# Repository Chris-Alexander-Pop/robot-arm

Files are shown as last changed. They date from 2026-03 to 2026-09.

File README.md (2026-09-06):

# 6-DOF Robot Arm

**Status:** early Checkpoint A ("It moves" on the bench) — not a working 6-DOF tending system.

Hobby / portfolio build: 3D-printed cycloidal joint CAD, an RS-485 motor bench, Hall homing on Arduino, and STM32 supervisory P-control for J1/J2. ROS 2 / MoveIt / Simulink trees exist as scaffolds. The headline application is not implemented.

**Stack:** STM32 (PlatformIO, P-only `JointController::Step`) · ESP32 joint-node parser · Pico + ESP32-C3 RS-485 benches · SolidWorks CAD · Python DH sandbox · ROS 2 Humble / MoveIt 2 *scaffolds* · Simulink *README only*



## Preview

<p align="center">
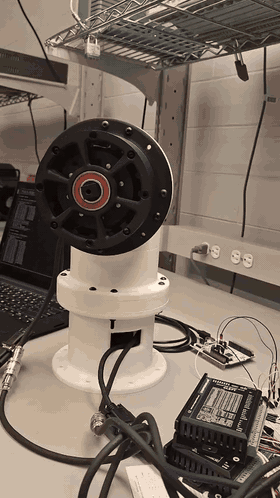
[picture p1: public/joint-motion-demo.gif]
Joint motion demo
  
</p>

<p align="center">
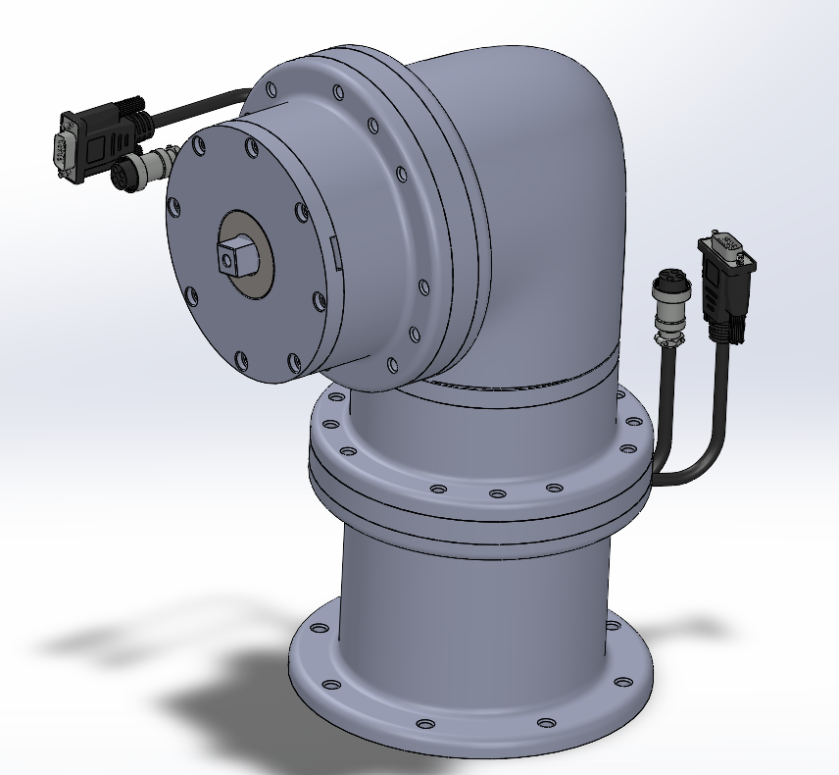
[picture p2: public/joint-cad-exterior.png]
Joint module — exterior CAD render
  
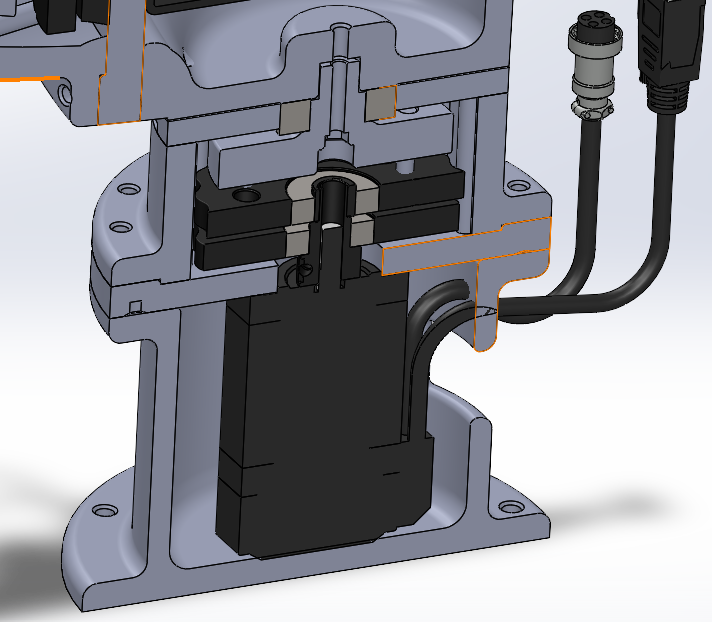
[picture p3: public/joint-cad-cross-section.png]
Joint module — cross-section CAD render
  
</p>

Bench motion clip (22–28 s from `20260516_220314_1_1.mp4`); CAD renders from SolidWorks.

## What actually works

- **Cycloidal joint CAD** under `mechanical/` — Maria is the primary CAD author (see Authorship).
- **RS-485 motor bench** — Pico master plus ESP32-C3 slaves, including a local Pico J0 STEP/DIR path on GP16/GP17: `firmware/scripts/hardware_tests/rs485_motor_bench/`.
- **Hall homing FSM** on Arduino: `firmware/scripts/hardware_tests/homing_arduino/src/main.ino`.
- **STM32 supervisory P-control** for J1/J2: `kDefaultKp = 2.0F`, Ki/Kd = 0, velocity cap `kMaxSupervisorVelocityDegS = 120.0F` in `firmware/stm32_core/lib/control/src/joint_controller.cpp`. Arduino `StepperDriver` uses AccelStepper for STEP/DIR. Native tests store commanded velocity only.
- **Native firmware tests** via `./firmware/scripts/test.sh`. **Renode smoke** in CI. **Python pytest** for the DH sandbox (`simulation/dh_solver.py`) and placeholder kinematics tests.

Gear ratios the controller uses: `kJ1MotorRevsPerJointRev = 19.0F`, `kJ2MotorRevsPerJointRev = 15.0F` in `firmware/stm32_core/lib/drivers/src/stepper_driver.cpp`. Physical cycloid pin/lobe counts are `[NEEDS MEASUREMENT]`.

## Not yet implemented

- `firmware/stm32_core/lib/bus/src/bus_master.cpp` — `BusMaster::Transaction` discards the frame and returns false (no RS-485 TX from the master).
- `firmware/joint_node/src/joint_node_app.cpp` — TODOs at the STEP/DIR + homing call site, gripper PWM, and homing FSM (`kHomePin`).
- `simulation/robot_arm_sim/kinematics/dh_model.py` — `forward_kinematics` returns the 4×4 identity.
- `software/ros2_ws/src/robot_description/urdf/mock_arm.urdf.xacro` — cylinder mock links, not CAD-derived geometry.
- `simulink/README.md` — planned Simulink / Embedded Coder tree; no `.slx` in the repo.
- `firmware/stm32_core/lib/drivers/src/encoder_driver.cpp` — MCU `ReadJointAngleDeg` returns 0.0 by design (position stays inside the CL57T/CL42T).

Checkpoint letters B–F in `docs/Application.md` are a delivery plan, not a progress report.

## Future application

The long-term target is **autonomous 3D-print bed tending** (detect completion, remove the part, start the next job). That application is not in this tree: there is no OctoPrint integration, no vision pick, and no end-to-end tending cycle. Treat it as a goal, not a capability.

## Architecture

| Layer | Location | Role today |
|---|---|---|
| Planning | `software/ros2_ws/` | ROS 2 / MoveIt 2 **scaffold** (Docker tests exist) |
| Real-time control | `firmware/stm32_core/` | UART protocol, P-only supervisor, AccelStepper on J1/J2 |
| Joint nodes | `firmware/joint_node/` | Parses bus commands; pulse generation is TODO |
| Simulation | `simulation/` | DH sandbox + identity FK placeholder + Renode smoke |
| Mechanical | `mechanical/` | SolidWorks; STEP exports where present |
| Electrical | `hardware/` | KiCad, WireViz, datasheet references |
| Model-based design | `simulink/` | README scaffold only |

Details: [`docs/ARCHITECTURE.md`](docs/ARCHITECTURE.md) · [`docs/Design_Choices.md`](docs/Design_Choices.md)

## Quickstart (~10 minutes)

**Prerequisites:** Git, Python 3.11+, [PlatformIO](https://platformio.org/) (`pio`), Docker (for ROS tests).

```bash
git clone https://github.com/Chris-Alexander-Pop/robot-arm.git
cd robot-arm
./scripts/setup.sh

# Firmware (host native tests — no hardware)
./firmware/scripts/test.sh

# Python simulation
./simulation/scripts/test.sh

# ROS / MoveIt (Docker; slower first run)
./scripts/dev.sh up
./scripts/dev.sh moveit-test
```

Full matrix: [`TESTING.md`](TESTING.md)

## Repository map

| Path | Contents |
|---|---|
| `docs/` | Requirements, architecture, journal |
| `mechanical/` | CAD (SolidWorks); see [`docs/implementation/cad_exports.md`](docs/implementation/cad_exports.md) |
| `hardware/` | KiCad, datasheets, WireViz |
| `firmware/` | STM32 C++ (PlatformIO), ESP32 joint_node, hardware benches |
| `software/` | ROS 2 workspace + Docker |
| `simulation/` | Python sim + Renode |
| `simulink/` | Planned MBD workspace (not in tree yet) |

## Verification (CI)

| Layer | Local | CI job |
|---|---|---|
| Firmware (native) | `./firmware/scripts/test.sh` | `firmware-native-tests` |
| Firmware (Renode) | build `nucleo_f401re_renode`, `simulation/renode/tests/firmware_smoke.robot` | `firmware-build-and-renode` |
| ROS / MoveIt | `./software/scripts/test.sh` | `software-behavioral-tests` |
| Simulation | `./simulation/scripts/test.sh` | `simulation-tests` |

## Team setup

- Linux/macOS: [`./scripts/setup.sh`](scripts/setup.sh)
- Windows: [`./scripts/setup.ps1`](scripts/setup.ps1)

Creates `simulation/.venv`, `.tooling/` ROS CLI tools, and Renode for headless firmware tests. Firmware uses PlatformIO, not a Python venv.

Dev helpers: [`./scripts/dev.sh`](scripts/dev.sh) / [`./scripts/dev.ps1`](scripts/dev.ps1) for Dockerized ROS.

## Authorship

`git shortlog -sne --all` on 2026-09-06 (measured before this README commit):

| Commits | Author |
|---:|---|
| 93 | Maria `<mnastase@uwaterloo.ca>` |
| 88 | Chris Alexander Pop `<chrisalexanderpop@gmail.com>` |
| 5 | dependabot[bot] |
| 4 | Fatima Syeda `<f2syeda@uwaterloo.ca>` |
| 1 | Cursor Agent `<cursoragent@cursor.com>` |

Maria is the primary CAD author. This is a shared build; firmware/bench work is not a solo project.

Re-run `git shortlog -sne --all` after new commits — do not copy these counts forward without measuring.

## Contributing

See [`CONTRIBUTING.md`](CONTRIBUTING.md) and [`firmware/CONTRIBUTING.md`](firmware/CONTRIBUTING.md). Remaining `TODO(contributor)` markers are intentional scaffolds, not abandoned files. `JointController::Step` is already P-only (not a stub).

## Licenses and third-party materials

- **Source code** (firmware, ROS, simulation, scripts): [MIT](LICENSE) — see [NOTICE](NOTICE).
- **Datasheets:** vendor URLs in [`hardware/datasheets/README.txt`](hardware/datasheets/README.txt) (PDFs not in git; download locally if needed).
- **CAD:** SolidWorks native files are proprietary format; STEP provided where applicable.
- **AccelStepper** (waspinator / Mike McCauley): GPL-3.0 or commercial — J1/J2 STEP/DIR on STM32.
- **StepperDriver** (laurb9): MIT — STEP/DIR helpers and declared `joint_node` dep.
- **MATLAB / Simulink:** optional future workflow; trademarks of The MathWorks, Inc.

## Security

Hobby / bench project only — see [`SECURITY.md`](SECURITY.md). Serial control has no authentication; use a trusted USB-UART link.

## Deep dive

- [`docs/Application.md`](docs/Application.md) — checkpoints A–F (plan, not current capability)
- [`docs/Examples.md`](docs/Examples.md) — comparison with AR4, Moveo, etc.

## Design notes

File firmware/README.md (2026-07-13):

# Firmware

Domain-level firmware for low-level embedded control: a **base STM32 master** and **ESP32 joint nodes** on a shared **RS-485** bus.

## Projects

| Directory | MCU | Role |
|:---|:---|:---|
| [`stm32_core/`](stm32_core/) | Nucleo-F401RE | Bus master, Pi UART protocol, future motion supervisor |
| [`joint_node/`](joint_node/) | ESP32 (WROOM-32 class) | Per-joint / gripper slave — **one firmware image**, multiple PlatformIO envs |
| [`lib/bus_protocol/`](lib/bus_protocol/) | — | Shared bus framing (linked by both projects) |

Architecture: [`docs/implementation/distributed_bus_architecture.md`](../docs/implementation/distributed_bus_architecture.md) · connectivity policy: [`docs/implementation/joint_node_connectivity.md`](../docs/implementation/joint_node_connectivity.md).

## Onboarding

- Contributor guide: **[CONTRIBUTING.md](CONTRIBUTING.md)**.
- Do **not** commit `compile_commands.json` under either PlatformIO project (see root `.gitignore`).
- Open the **specific** folder (`stm32_core/` or `joint_node/`) as the PlatformIO project root in VS Code.

## Build

Linux/macOS:

```bash
./firmware/scripts/build.sh              # STM32 + joint_node default env
./firmware/scripts/build.sh stm32        # STM32 only (compile, no flash)
./firmware/scripts/build.sh joint        # joint_node default env only
./firmware/scripts/build.sh joint-all    # all node_j* + node_gripper envs
```

Windows: `firmware/scripts/build.ps1` with the same optional arguments.

## Flash STM32 (Nucleo-F401RE)

Main application firmware lives in [`stm32_core/`](stm32_core/) (`src/main.cpp`). PlatformIO board/env: **`nucleo_f401re`** in [`stm32_core/platformio.ini`](stm32_core/platformio.ini). Upload uses onboard **ST-Link** (`upload_protocol = stlink`).

```bash
./firmware/scripts/upload_stm32.sh           # build + flash
./firmware/scripts/upload_stm32.sh monitor   # flash, then serial monitor @ 115200
```

Manual equivalent:

```bash
cd firmware/stm32_core
pio run -e nucleo_f401re -t upload
pio device monitor -e nucleo_f401re
```

If upload fails with `unable to connect` / `chipid 0x000`, run
[`firmware/scripts/hardware_tests/check_nucleo_stlink.sh`](scripts/hardware_tests/check_nucleo_stlink.sh)
(CN2 jumpers must be ON).

**Hardware tests** (RS-485, CL57T bench, Hall, etc.) are separate images built from
`hardware_test_main.cpp` under env **`nucleo_f401re_hwtest`** — see
[`scripts/hardware_tests/README.md`](scripts/hardware_tests/README.md).

## Test

```bash
./firmware/scripts/test.sh    # native unit tests (STM32 tree, includes bus_protocol)
```

## Flash joint nodes

```bash
cd firmware/joint_node
pio run -e node_j3 -t upload
pio device monitor
```

Unconfigured bench builds: `pio run -e esp32dev -t upload`, then serial command `NODE_ID 3`.

## Scope

- Real-time STEP/DIR and homing at the **joint node** (ESP32).
- RS-485 command/telemetry between base and nodes.
- Pi ↔ STM32 binary protocol unchanged in purpose (`lib/protocol/`).

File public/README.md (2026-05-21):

# Public media assets

README-linked visuals (committed for GitHub and local viewing).

| File | Source |
|---|---|
| `joint-cad-exterior.png` | `image.png` — SolidWorks exterior render |
| `joint-cad-cross-section.png` | `image2.png` — SolidWorks cross-section |
| `joint-motion-demo.gif` | `20260516_220314_1_1.mp4` @ 22–28 s (8 fps, 280 px wide) |
| `preview.html` | Browser gallery when Cursor preview hides images |

## Viewing in Cursor

Cursor’s default markdown renderer often **does not show local images** (forum: [local images bug](https://forum.cursor.com/t/default-cursor-markdown-renderer-fails-to-display-local-remote-images-vs-code-markdown-preview-works/160156), [feature request](https://forum.cursor.com/t/show-images-in-markdown-preview-mode/151125)).

**Option A — VS Code-style preview (recommended)**

1. Open root `README.md`.
2. If you see a WYSIWYG/preview tab, right-click the tab → **Reopen Editor With…** → **Text Editor**.
3. `Ctrl+K V` (**Markdown: Open Preview to the Side**).

**Option B — Browser**

Open `public/preview.html` in Firefox/Chrome (from the file explorer or `xdg-open public/preview.html`).

This repo sets `"workbench.editorAssociations": { "*.md": "default" }` so `.md` files prefer the text editor.

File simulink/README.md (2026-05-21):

# Simulink Workspace

> **Planned — not yet in repository**  
> MATLAB/Simulink models (`.slx`), Embedded Coder output under `codegen/output/`, and the firmware adapter described in docs are **not checked in**. Firmware today uses **hand-coded** control in `firmware/stm32_core/lib/control/`. See [`docs/implementation/simulink_workflow.md`](../docs/implementation/simulink_workflow.md).

Model-based design and embedded code generation for the 6-DOF arm. This workspace is the **control-design and codegen** counterpart to the Python/Gazebo workspace under `/simulation/`.

For the full workflow rationale, conventions, and toolbox requirements, see [`../docs/implementation/simulink_workflow.md`](../docs/implementation/simulink_workflow.md).

---

## Role in the Project

Simulink has three jobs here:

1. **Plant modeling** (`plant_models/`) — Simscape Multibody model of a joint built from the project URDF. Captures motor electrical dynamics, cycloidal reduction (with backlash + friction), and link inertia.
2. **Controller design** (`controllers/`) — Per-joint PID (and optional feed-forward / gravity-comp) designed and tuned against the plant model using PID Tuner. Output is a controller subsystem block ready for code generation.
3. **Embedded code generation** (`codegen/`) — Embedded Coder generates C source for the controller, which is linked into the PlatformIO STM32 firmware build under `firmware/stm32_core/lib/control/`.

A stretch goal is **co-simulation with ROS 2** via ROS Toolbox: Simulink plant model subscribes to `/joint_commands` from MoveIt and publishes simulated `/joint_states` back, letting controller iteration happen without spinning up Gazebo.

---

## Layout

```
simulink/
├── README.md                     # ← this file
├── plant_models/                 # Simscape Multibody / transfer-function plants
│   └── README.md
├── controllers/                  # PID + feed-forward controller designs (.slx)
│   └── README.md
├── codegen/                      # Embedded Coder configuration and generated C output
│   └── README.md
├── scripts/                      # MATLAB .m setup scripts (workspace init, param loading)
│   └── README.md
└── tests/                        # Test harnesses (unit + integration test models)
    └── README.md
```

The actual `.slx` model files are authored in MATLAB — this directory is the agreed home for them. **When codegen is implemented**, generated C under `codegen/output/` may be checked in so the firmware build does not require a MATLAB license; that output is **not in the repository yet**.

---

## Requirements

- **MATLAB R2024a or newer**
- **Simulink** (block-diagram environment)
- **Simscape** + **Simscape Multibody** (plant modeling)
- **Control System Toolbox** (PID Tuner)
- **Embedded Coder** + **Simulink Coder** (C code generation for STM32)
- **MATLAB Coder** (transitive dependency of Embedded Coder)
- *(optional)* **ROS Toolbox** — only required for the ROS 2 co-simulation stretch goal

Toolbox licensing: campus / educational MATLAB licenses typically include Simscape, Control System, and Embedded Coder. If running on a personal home license, verify Embedded Coder is included before relying on the codegen path.

---

## Onboarding

1. Open MATLAB and `cd` to this directory.
2. Run `scripts/setup_workspace.m` to load joint parameters (motor specs, gear ratios, link inertias) from the project constants into the MATLAB base workspace.
3. Open the plant model under `plant_models/joint_J1_plant.slx`.
4. Open the corresponding controller `controllers/joint_J1_pid.slx` and run PID Tuner to refine gains.
5. To regenerate C code, open `codegen/joint_pid_codegen.slx`, run `Build` (Ctrl+B); the generated source appears under `codegen/output/` and is committed.

---

## Integration with the firmware build

Generated C from Embedded Coder is dropped into `firmware/stm32_core/lib/control/generated/` and wrapped by a hand-written adapter (`joint_controller_generated.cpp`) that bridges the generated function signatures to the rest of the firmware. See [`../docs/implementation/firmware_architecture.md §2b`](../docs/implementation/firmware_architecture.md) for the integration contract.

The firmware build does **not** require MATLAB — only the regeneration of controller code does. This keeps the project buildable for collaborators without MATLAB licenses.

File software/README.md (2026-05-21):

# Raspberry Pi Software

High-level robot orchestration stack.

## Layout
- `ros2_ws/src/robot_core`: runtime control package.
- `ros2_ws/src/robot_description`: URDF/launch/rviz assets.
- `ros2_ws/src/robot_arm_moveit`: MoveIt 2 configuration and smoke tests.
- `Dockerfile`, `docker-compose.yml`: reproducible dev/runtime environment.

## Onboarding
- Start the ROS container with `./scripts/dev.sh up` from the repository root.
- Build the ROS workspace with `software/scripts/build.sh` on Linux/macOS.
- Build the ROS workspace with `software/scripts/build.ps1` on Windows.
- Run the MoveIt smoke tests with `software/scripts/test.sh` on Linux/macOS.
- Run the MoveIt smoke tests with `software/scripts/test.ps1` on Windows.

## MoveIt Bringup
- Use `./scripts/dev.sh moveit-sim` to build the workspace and launch the MoveIt + RViz simulation entry point.
- Use `./scripts/dev.sh moveit-real` to build the workspace and launch the MoveIt + RViz real-hardware entry point.

## STM32 Simulation
- Use Renode as the preferred STM32F401RE emulator for firmware-level integration tests.
- Keep the simulator entry points and test harnesses in this area so the MCU can be exercised without a physical board.
- Use the simulation package for kinematics and trajectory logic; use Renode for firmware behavior and peripheral interaction.
- Prefer headless/console mode so Renode prints to the terminal instead of opening separate analyzer windows.

## MoveIt
- `ros2_ws/src/robot_arm_moveit` holds the MoveIt 2 config package, launch entrypoint, and smoke tests.
- `sim.launch.py` and `real.launch.py` are the documented entry points; both currently wrap the shared headless MoveIt bringup and add RViz.
- Use the MoveIt launch file for planner bringup once the ROS 2 MoveIt runtime is installed in the container or host environment.

Generated ROS artifacts in `ros2_ws/build`, `ros2_ws/install`, and `ros2_ws/log` should not contain source code.

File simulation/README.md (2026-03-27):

# Simulation Workspace

Python-first sandbox for validating kinematics and trajectory behavior before hardware deployment.

## Layout
- `robot_arm_sim/`: simulation package code.
- `scripts/`: executable entry scripts for local runs.
- `tests/`: unit tests for kinematics/planning components.
- `dh_solver.py`: initial DH prototype script.
- `requirements.txt`: Python dependencies.

## Onboarding
- Create the virtual environment with the repository setup scripts.
- Run tests on Linux/macOS with `simulation/scripts/test.sh`.
- Run tests on Windows with `simulation/scripts/test.ps1`.

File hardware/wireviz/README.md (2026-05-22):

# WireViz harness diagrams

Text-based wiring docs for the 6-DOF arm. YAML in, SVG / HTML / PNG out via [WireViz](https://github.com/wireviz/WireViz).

## What is in here

| File | Scope |
|---|---|
| `10_power_distribution.yml` | AC mains, IEC inlet, E-stop, Mean Well LRS-350-24, 24V_MOTOR bus, three LM2596 buck rails. |
| `20_control_signals.yml` | STM32 Nucleo-F401RE pins, 74HC245 level shift, six driver control headers, Pi UART link. |
| `30_joint_J1_closed_loop.yml` | Detail of one closed-loop joint (CL57T + NEMA 23 + **factory encoder bundled with the kit**). Pattern repeats for J1–J4 (CL42T for J3/J4). |
| `40_joint_J5_open_loop.yml` | Detail of one open-loop wrist joint (TMC2209 + NEMA 14). AS5600 shown as an optional Phase 2 part — most builds skip it. Same shape for J6. |
| `50_homing.yml` | Six A3144 Hall sensors — each to its **ESP32 joint node** (local homing; STM32 issues bus `HOME`). |
| `35_bus_harness.yml` | RS-485 + 24V daisy chain through the arm (distributed nodes). |
| `55_wrist_encoders.yml` | Optional Phase 2 path: STM32 I2C to TCA9548A and two AS5600 boards (J5/J6 only). Omit entirely if you skip wrist encoders. |
| `60_end_effector.yml` | MG996R gripper servo (mounts inside the gripper body, not the arm), `5V_SERVO` rail, PWM signal across the J6 tool flange, optional FSR. |

These follow the contracts in:

- [`docs/implementation/electrical_design.md`](../../docs/implementation/electrical_design.md)
- [`docs/implementation/electrical_interface_map.md`](../../docs/implementation/electrical_interface_map.md)
- [`firmware/pinout.md`](../../firmware/pinout.md)

WireViz is intentionally **per-harness**, not whole-system. A high-level block view lives in `electrical_schematic_plan.md` §1 and the Mermaid sketch at the bottom of this README.

## Prerequisites

- Python 3 (the venv script makes one).
- **Graphviz** (`dot`) on your PATH. WireViz fails to render without it.
  - Arch: `pacman -S graphviz`
  - Debian/Ubuntu: `apt install graphviz`

## One-time environment

From the repository root:

```bash
./scripts/create-wireviz-venv.sh
```

Activate when needed:

```bash
source hardware/wireviz/.venv/bin/activate
```

Windows (PowerShell):

```powershell
.\scripts\create-wireviz-venv.ps1
.\hardware\wireviz\.venv\Scripts\Activate.ps1
```

## Render everything

From the repo root:

```bash
./scripts/render-wireviz.sh           # all *.yml in hardware/wireviz/, HTML+SVG
./scripts/render-wireviz.sh -c -q     # clean out/ first, quiet per-file output
./scripts/render-wireviz.sh -f hsp    # also write PNG
```

Windows (PowerShell):

```powershell
.\scripts\render-wireviz.ps1 -Clean -Quiet
.\scripts\render-wireviz.ps1 -Formats hsp
```

The script picks up every `*.yml` except `_common.yml` (prepended into every render for shared Graphviz spacing and colors). Drop a new harness file in here and rerun. Output goes to `out/` (gitignored).

Render a single file:

```bash
./scripts/render-wireviz.sh 30_joint_J1_closed_loop          # by basename
./scripts/render-wireviz.sh hardware/wireviz/55_wrist_encoders.yml  # by path
```

Or call WireViz directly if you prefer:

```bash
source hardware/wireviz/.venv/bin/activate
cd hardware/wireviz
wireviz 10_power_distribution.yml -o out -O 10_power_distribution -f hs
```

`-f hs` writes both **HTML** (with a BOM table) and **SVG** (lossless graphic). Add `p` for PNG, `t` for TSV.

## How to view the diagrams

The diagrams are SVG, so anything that opens an image or web page works:

- **Browser (recommended)** – open the HTML for the BOM + diagram inline:
  ```bash
  xdg-open out/10_power_distribution.html       # Linux
  open out/10_power_distribution.html           # macOS
  start out\10_power_distribution.html          # Windows (cmd)
  ```
- **Just the diagram** – open the SVG directly:
  ```bash
  xdg-open out/10_power_distribution.svg
  ```
- **VS Code / Cursor** – open the SVG file; the editor renders it. Right-click an SVG in the Explorer ➜ *Open Preview*.
- **Image viewer** – Eye of GNOME, qView, IrfanView, Preview, etc.
- **Static site / share** – the SVG and HTML are self-contained; you can drop them into any docs folder or email them.

If you only see XML when opening the SVG, your default app is a text editor — pick a browser or image viewer instead.

## Authoring rules learned the hard way

WireViz emits Graphviz DOT under the hood. Two pitfalls cause render failures:

1. **No leading digits in identifiers or labels.** Use `P5V_LOGIC`, not `+5V_LOGIC`. Use `P24V`, not `+24V`. Same for cable IDs (`W_PWR_LOGIC`, not `W_5V_LOGIC`).
2. **No `<` or `>` characters in `subtype:` / `notes:` text.** They terminate the HTML label early. Write `to` instead of `->`, `at least 3 A` instead of `>=3 A`.

Other conventions used here:

- **`_common.yml`** — shared `options:` and a small `tweak.append` graph directive (`nodesep`, `ranksep`) so diagrams space out consistently. Large motor drivers are split into several logical connector blocks (same physical CL57T or TMC2209) so WireViz does not draw one 15–20-pin vertical tower.
- Wire colors follow the [WireViz color codes](https://github.com/wireviz/WireViz/blob/master/docs/syntax.md#wire-colors) (`RD`, `BK`, `WH`, etc.).
- Every cable that crosses the cabinet boundary is `shield: true`.
- Joint-by-joint cables (`W_CTRL_J1` … `W_CTRL_J6`) use the same color code so a real harness label survives a swap between channels.

## Where the system view lives

WireViz is bad at one-page “whole robot” views. Use this Mermaid block diagram (rendered automatically by GitHub / VS Code / Cursor) as the index:

```mermaid
flowchart LR
  MAINS[AC mains] --> IEC[IEC C14 + fuse]
  IEC --> ESTOP[Latching E-stop]
  ESTOP --> PSU[Mean Well LRS-350-24]
  PSU --> BUS24[24V_MOTOR bus]
  BUS24 --> DRV[Drivers J1..J6]
  BUS24 --> BUCKL[LM2596 5V_LOGIC]
  BUS24 --> BUCKP[LM2596 5V_PI]
  BUS24 --> BUCKS[LM2596 5V_SERVO]
  BUCKL --> MCU[STM32 Nucleo-F401RE]
  BUCKL --> HALL[A3144 Hall homes x6]
  BUCKP --> PI[Raspberry Pi 4]
  BUCKS --> GRIP[MG996R gripper - mounts in EOAT, not arm]
  MCU -- UART --> PI
  MCU -- STEP/DIR/EN/ALARM --> DRV
  MCU -- HOME x6 --> HALL
  MCU -- PWM --> GRIP
  DRV --> MOT[Joint motors]
  MOT -. factory encoder J1-J4 inside CL57T/CL42T kit .- DRV
```

For pin-accurate detail, jump into the matching YAML and re-render.

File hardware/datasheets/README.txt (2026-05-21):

Vendor datasheet URLs for the robot arm BOM. PDFs are NOT stored in git (copyright).

Download locally into this folder if you want offline copies (files are gitignored):

  cd hardware/datasheets
  # example: curl -L -o TI_LM2596.pdf 'https://www.ti.com/lit/ds/symlink/lm2596.pdf'

If a download fails (TLS to st.com / ti.com can be flaky), open the link in a browser.

Power / analog / logic
  meanwell_LRS-350-spec.pdf
    https://www.meanwell.com/upload/pdf/LRS-350/LRS-350-SPEC.PDF
  TI_LM2596.pdf
    https://www.ti.com/lit/ds/symlink/lm2596.pdf
  TI_SN74HC245.pdf
    https://www.ti.com/lit/ds/symlink/sn74hc245.pdf
  TI_TCA9548A.pdf
    https://www.ti.com/lit/ds/symlink/tca9548a.pdf

Motors / drivers
  StepperOnline_CL57T_V40.pdf   (family doc; confirm against your V41 kit)
    https://www.omc-stepperonline.com/download/CL57T_V4.0.pdf
  StepperOnline_CL42T_manual.pdf
    https://www.omc-stepperonline.com/download/CL42T.pdf
  Trinamic_TMC2209_DigiKey_rev108.pdf   (Trinamic / Analog IC - verify YOUR breakout pins)
    https://mm.digikey.com/Volume0/opasdata/d220001/medias/docus/696/TMC2209_Rev.1.08.pdf

Sensors / homing
  Allegro_A314x.pdf   (A3144 family - legacy; consider a modern Hall part for new buys)
    https://www.allegromicro.com/~/media/Files/Datasheets/A3141-2-3-4-Datasheet.ashx
  AMS_AS5600.pdf   (AMS OSRAM AS5600 - Seeed-hosted copy)
    https://files.seeedstudio.com/wiki/Grove-12-bit-Magnetic-Rotary-Position-Sensor-AS5600/res/Magnetic%20Rotary%20Position%20Sensor%20AS5600%20Datasheet.pdf

MCU / board   (prefer official ST links in a browser)
  ST_RM0368_DM00096844_mirror.pdf   RM0368 reference manual for STM32F401xB/C/D/E
    Official: https://www.st.com/resource/en/reference_manual/dm00096844-stm32f401xb-c-and-stm32f401xd-e-advanced-arm-based-32-bit-mcus-stmicroelectronics.pdf
  ST_Nucleo64_UM1724_DM00105823_mirror.pdf   Nucleo-64 boards (MB1136), incl. NUCLEO-F401RE
    Official: https://www.st.com/resource/en/user_manual/dm00105823-stm32-nucleo64-boards-mb1136-stmicroelectronics.pdf

STM32F401RE chip datasheet:
  https://www.st.com/resource/en/datasheet/stm32f401re.pdf

MG996R gripper: no single vendor PDF; use seller diagrams + standard 3-wire hobby servo (GND, +5V, PWM).

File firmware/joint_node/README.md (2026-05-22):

# Joint node firmware (ESP32)

Distributed motor nodes: one small **ESP32** module per joint (and one for the gripper), co-located with the stepper driver. Nodes communicate on a **daisy-chained RS-485 bus** (2 twisted pairs for data + 24V/GND for power through the arm).

**Connectivity policy:** RS-485 is the **control plane** (motion, homing, watchdog). **Wi-Fi** is an optional **service plane** (config, logs, OTA) and must be **disabled during motion**. See [`../../docs/implementation/joint_node_connectivity.md`](../../docs/implementation/joint_node_connectivity.md).

## One firmware image

All nodes build from the **same source tree**. Identity is selected by:

1. **PlatformIO environment** (`node_j1` … `node_j6`, `node_gripper`) — sets `ROBOT_ARM_NODE_ID` at compile time (recommended for production).
2. **GPIO strap pins** (optional carrier PCB) — 3-bit ID when straps are populated.
3. **NVS** — persist `NODE_ID <n>` from the USB serial console (`esp32dev` / unconfigured flash).
4. **Console** — `NODE_ID 4` at runtime for bench bring-up.

## PlatformIO

Open **`firmware/joint_node/`** as the project root in VS Code.

```bash
cd firmware/joint_node
pio run -e node_j3          # build joint 3
pio run -e node_gripper -t upload
pio device monitor
```

Default env `esp32dev` leaves `ROBOT_ARM_NODE_ID=0` until configured.

## Pin map

See [`src/pinout.h`](src/pinout.h). Revise when joint carrier PCBs are laid out.

## Protocol

Shared library: [`../lib/bus_protocol/`](../lib/bus_protocol/). Full specification: [`../../docs/implementation/distributed_bus_architecture.md`](../../docs/implementation/distributed_bus_architecture.md).

## Homing (Hall sensor)

Each motor joint (IDs 1–6) has an **A3144** on `kHomePin` (see [`src/pinout.h`](src/pinout.h)). When the base STM32 sends bus command **`HOME`** (`0x23`) to this node's address, the firmware must:

1. Enable the local driver and STEP toward the configured home direction at low speed.
2. Stop on Hall trigger (active-low), zero position / step count, set homed state.
3. Report completion in the next `JOINT_STATE` response to the master poll.

The STM32 sequences homing **J1 → J6**; the Pi only sees `HOME` / `HOMED_OK` on the UART link. The gripper node does not use Hall homing.

## Wi-Fi service mode (planned)

Not implemented yet. When added:

- **MOTION** — Wi-Fi off; only RS-485 + local STEP/DIR.
- **SERVICE** — Wi-Fi on for NVS config, logs, OTA; driver disabled by default; **no** motion over Wi-Fi.

## Status

Scaffold only: bus framing, RS-485 port, enable/watchdog, and command stubs. STEP/DIR motion, **Hall homing FSM**, servo PWM, and **Wi-Fi service mode** are TODO.

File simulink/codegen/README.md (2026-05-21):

# Embedded Codegen

> **Planned — not yet in repository**  
> No `codegen/output/`, wrapper `.slx`, or firmware adapter is checked in yet. See [`../../docs/implementation/simulink_workflow.md`](../../docs/implementation/simulink_workflow.md).

Embedded Coder configuration and generated C source for the joint controllers. **Target state:** generated code checked in so the firmware (`firmware/stm32_core/`) can build without a MATLAB license.

## Layout

```
codegen/
├── README.md                     # ← this file
├── joint_pid_codegen.slx         # Wrapper model with codegen configuration
├── ert_main.tmpl                 # Custom main template (we provide our own integration)
└── output/                       # Generated C (COMMITTED)
    ├── joint_J1_pid/
    │   ├── joint_J1_pid.c
    │   ├── joint_J1_pid.h
    │   └── joint_J1_pid_types.h
    └── joint_J2_pid/
        └── ...
```

## Code Generation Settings

The wrapper model `joint_pid_codegen.slx` references the controllers from `../controllers/` and applies the following Embedded Coder configuration:

| Setting | Value | Why |
|:--|:--|:--|
| System target file | `ert.tlc` (Embedded Real-Time) | Generates production-quality C, not the larger GRT runtime |
| Hardware Implementation | ARM Cortex-M | Matches STM32 target |
| Floating point support | Single precision (`float32`) | Matches STM32F4 FPU |
| Generate reusable code | On | Lets us call the same function for multiple joints with different parameter structs |
| Pack Boolean data into bitfields | Off | Keeps the generated code easy to inspect in code review |
| File packaging format | Modular | One .c/.h per subsystem, not a single monolithic file |
| Code interface | Reusable function with parameter argument | Generated signature matches the hand-written firmware adapter |

## Integration with PlatformIO firmware

Generated source under `output/` is symlinked (or copied — TBD) into:

```
firmware/stm32_core/lib/control/generated/
```

A hand-written adapter at `firmware/stm32_core/lib/control/src/joint_controller_generated.cpp` instantiates one parameter struct per joint, calls the generated step function at 1 kHz from the existing `JointController::Step` hook, and routes the output back into the existing `StepperDriver` pulse-rate setpoint. The adapter is the **only** hand-written firmware code that touches the generated functions — everything else in the firmware stays decoupled.

This boundary is enforced so a future controller redesign (e.g., switching to LQR) does not require firmware changes outside the adapter.

## Regeneration

```matlab
% From simulink/codegen/:
load_system('joint_pid_codegen.slx');
rtwbuild('joint_pid_codegen');
```

After regeneration, commit `output/` along with the `.slx` change.

**Never edit files under `output/` by hand.** They are overwritten on every regeneration. If you need to change controller behavior, edit the model in `../controllers/`.

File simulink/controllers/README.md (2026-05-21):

# Controllers

> **Planned — not yet in repository** — no `.slx` controller models are checked in. See [`../../docs/implementation/simulink_workflow.md`](../../docs/implementation/simulink_workflow.md).

Per-joint controller designs (PID + optional feed-forward / gravity-comp). Each controller is designed against the corresponding plant model in `../plant_models/`, tuned with PID Tuner, and built into a self-contained subsystem block ready for Embedded Coder.

## Planned controllers

| File | Joint | Topology |
|:--|:--|:--|
| `joint_J1_pid.slx` | J1 | Cascaded position → velocity PID; anti-windup; saturation limits |
| `joint_J2_pid.slx` | J2 | Same topology as J1, plus a gravity-compensation feed-forward term (J2 carries the rest of the arm against gravity) |
| `joint_generic_pid.slx` | J3 – J6 | Single-loop position PID parameterized by motor/load constants — one model, many uses |
| `arm_trajectory_tracker.slx` | All 6 | Top-level controller that consumes a MoveIt-style joint trajectory and dispatches setpoints to the per-joint PIDs |

## Design discipline

- **Same controller runs in sim and on hardware.** The controller subsystem is the *exact* block that gets code-generated. No "Simulink-only" simplifications allowed — if a block can't be code-generated by Embedded Coder, it can't be in the controller.
- **Discrete-time, 1 kHz.** All controllers run at the firmware's PID loop rate (`docs/Constraints.md §3a`). Continuous-time blocks (e.g., `Integrator`) are replaced with their discrete equivalents (`Discrete-Time Integrator`).
- **Fixed-step solver, fixed-point safe.** Solver is `Fixed-step, Discrete (no continuous states)`. Where possible, data types are `single` (float32) to match what the STM32 FPU handles natively.
- **All gains exposed as tunable parameters.** Gains are referenced from the MATLAB base workspace (`Kp_J1`, `Ki_J1`, etc.), populated by `scripts/setup_workspace.m`. This makes them runtime-tunable from the firmware once the generated code is integrated, and keeps them out of the model XML.

## Tuning workflow

1. Open `joint_J1_pid.slx` connected to `joint_J1_plant.slx` in a closed loop.
2. Apply a step setpoint (e.g., 45° at t=0.1s).
3. Open PID Tuner on the PID block; tune for the response goal in `docs/Constraints.md` (rise time, overshoot, settling time).
4. Validate against a worst-case load disturbance (rated payload at full extension).
5. Commit the model with updated gains in the workspace setup script.

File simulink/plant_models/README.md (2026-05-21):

# Plant Models

> **Planned — not yet in repository** — no `.slx` plant models are checked in. See [`../../docs/implementation/simulink_workflow.md`](../../docs/implementation/simulink_workflow.md).

Simscape Multibody plant models of the arm joints. Each model captures the full electromechanical chain from driver step-pulse input to joint-angle output.

## Planned models

| File | Joint | Source dynamics |
|:--|:--|:--|
| `joint_J1_plant.slx` | J1 (Base) | NEMA 23 + CL57T (modeled as torque-speed curve) + 20:1 cycloidal (with backlash + viscous friction) + base-link inertia |
| `joint_J2_plant.slx` | J2 (Shoulder) | NEMA 23 + CL57T + 20:1 cycloidal + upper-arm inertia (gravity-loaded) |
| `arm_full_plant.slx` | All 6 | Simscape Multibody chain imported from URDF (`software/ros2_ws/src/robot_description/urdf/mock_arm.urdf.xacro`) |

## URDF import workflow

```matlab
% From the simulink/scripts/ directory:
smimport('../../software/ros2_ws/src/robot_description/urdf/mock_arm.urdf.xacro')
```

`smimport` produces a Simscape Multibody model with one Revolute Joint block per URDF joint. The imported model is then hand-augmented with:

- Motor torque-speed curves (from datasheets in `hardware/datasheets/`)
- Cycloidal backlash (modeled as a small dead-zone on torque transmission)
- Viscous + Coulomb friction (tuned to match real arm behavior — this is one of the URDF parameters that gets refined per the "simulation is the specification" philosophy)

## Validation

Plant models are validated against the constraints in [`../../docs/Constraints.md §1a`](../../docs/Constraints.md):

- Apply rated motor torque (2.0 Nm for NEMA 23) at the input.
- Verify output torque after 20:1 reduction matches the documented 40 Nm effective.
- Verify steady-state holding error under a 1 kg payload at full extension is within the ±0.5–1 mm repeatability target.

Mismatches between the plant model and the real arm get logged in [`../../docs/Journal.md`](../../docs/Journal.md) and drive URDF refinements.

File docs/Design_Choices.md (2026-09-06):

<!--
This file holds the design choices made for this project and their engineering reasoning.
Decisions are recorded here so the rationale is preserved across development phases.
-->

# Design Choices & Engineering Rationale

This document records the key design decisions for the 6-DOF robot arm, focusing on **why** each choice was made over the alternatives. Decisions are organized by subsystem.

---

## 1. Mechanical & Actuation

### 1a. Cycloidal Drives at J1–J4

**Decision**: Use **3D-printable cycloidal drives** (PETG disk + hardened steel dowel ring pins) at all four driven joints. Firmware authority for J1/J2 is 19:1 and 15:1 (`kJ1MotorRevsPerJointRev = 19.0F`, `kJ2MotorRevsPerJointRev = 15.0F`); physical counts `[NEEDS MEASUREMENT]`. J3/J4 remain design-intent 15:1 and 10:1.

**Alternatives Considered**:

| Option | Pros | Cons | Chosen? |
|:---|:---|:---|:---:|
| Planetary Gearbox (metal, off-shelf) | Very robust, no printing | Expensive (~$80–$150 per joint), heavy | ✗ |
| Harmonic Drive | Near-zero backlash, compact | Extremely expensive (~$300+) | ✗ |
| Worm Gear (3D printed) | Self-locking, cheap | High friction, low efficiency, no backdrivability | ✗ |
| Timing Belt only (J3) | Cheap, no extra housing | 3:1 belt = 2.4 Nm — **below the 3.27 Nm requirement** | ✗ |
| **Cycloidal Drive (3D printed + steel pins)** | Printable, single-stage ratios in the ten-to-twenty range, high torque density, near-zero backlash, uniform BOM | Requires PTFE grease, careful tolerances, eccentric vibration must be managed | **✓** |

**Rationale**: The cycloidal drive achieves a high ratio in a package smaller than a fist. The ring gear pins are hardened steel M4 dowels — these cannot shear; only the PETG disk is consumable. Extending cycloidals to J3 and J4 resolves the torque shortfall (see `Calculations.md §1e`) and **unifies the entire drive system**: the same dowel pins, the same print profiles, and the same assembly procedure across all four joints, simplifying fabrication and spares.

---

### 1b. NEMA 23 for J1 & J2, Not Larger (e.g. NEMA 34)

**Decision**: Use the **2.0 Nm NEMA 23** closed-loop kits as the base/shoulder motors.

**Rationale**: Firmware J2 reduction is 15:1 (`kJ2MotorRevsPerJointRev`); physical `[NEEDS MEASUREMENT]`. Output torque at J2 is `[NEEDS MEASUREMENT]` — do not reuse the old 2.0 Nm × 20 = 40 Nm figure, which used a superseded twenty-to-one design target. Going to NEMA 34 would provide more torque but:
- Larger, heavier, physically larger envelope (harder to integrate into the cycloidal housing)
- Far more expensive
- Drivers would need to operate at 5–8A, requiring a larger PSU
- Even at the firmware 15:1 (J2) / 19:1 (J1) values, PETG structural strength remains the likely limit; that comparison is unmeasured.

---

### 1c. NEMA 14 "Pancake" Motors for J5 & J6 (Wrist/Tool)

**Decision**: Use the **14HS10-0404S** NEMA 14, 26mm-long pancake steppers for joints 5 and 6.

**Rationale**: At the wrist, every gram of motor mass multiplies into additional required torque at J2 (lever arm effect). A NEMA 17 at the wrist (280g) would add ~1.5 Nm to the J2 load. The 14HS10-0404S weighs **130g** — half the NEMA 17 — and the wrist torque requirement is only ~0.15 Nm (well within its 0.14 Nm rating at low speeds, augmented by any small gearing if needed).

The wrist joints do not need the high torque of a closed-loop system, so the open-loop TMC2209 driver is sufficient. The TMC2209's **StealthChop** mode eliminates audible stepping noise, which would otherwise be very noticeable at the wrist where motor mounts are near the user.

---

### 1d. Cycloidal Drive at J3 (Elbow) — 15:1

**Decision**: Replace the originally considered GT2 belt drive at J3 with a **15:1 cycloidal drive** on the NEMA 17 (80 Ncm) motor.

**Why not belt?**
The worst-case torque at J3 is **3.27 Nm**. A 3:1 GT2 belt drive (the practical maximum before pulleys become geometrically oversized) yields only `0.80 Nm × 3 = 2.40 Nm` — a shortfall of ~27%. Increasing to 4:1 is possible but results in a 64-tooth driven pulley that is physically larger than the NEMA 17 motor body, making packaging very difficult inside the upper arm link.

**Why 15:1 specifically?**
- Yields `0.80 × 15 = 12.0 Nm` — a 3.67× safety factor over the 3.27 Nm requirement
- 15 pins is a smaller, lighter housing than the 20-pin J1/J2 design, appropriate for the NEMA 17
- 15:1 keeps motor input speed at a moderate RPM for typical joint velocities (below the estimated 1116 RPM structural resonance threshold)

**Trade-off accepted**: The cycloidal housing adds ~50–80g to Link 1 (upper arm), slightly increasing J2 load. Firmware J2 reduction is 15:1; whether that absorbs the extra mass is `[NEEDS MEASUREMENT]` (the old 40 Nm figure used a superseded twenty-to-one target).

---

### 1e. Cycloidal Drive at J4 (Forearm Twist) — 10:1

**Decision**: Use a **10:1 cycloidal drive** on the NEMA 17 (42 Ncm) motor at J4.

**Is a gearbox even necessary at J4?** The gravity torque at J4 is near-zero (the rotation axis is roughly parallel to the forearm, so the distal mass creates no gravitational moment). However, a cycloidal drive at J4 is still chosen for three reasons:

1. **Resolution**: Direct drive at 1/32 microstepping gives 0.056°/step. Through a 10:1 cycloidal, that becomes 0.0056°/step — 10× finer, enabling precise tool-roll positioning for orientation-sensitive pick-and-place.
2. **Inertial damping**: The gear reduction lowers effective reflected inertia at the output, reducing oscillation after a direction reversal — important for a lightweight wrist assembly that has little natural damping.
3. **Manufacturing uniformity**: Using the same ring pins, grease, and assembly procedure as J1/J2/J3 reduces the number of unique part types in the BOM.

**Ratio choice**: 10:1 (10 pins, 9-lobe disk) is the smallest practical cycloidal ratio. Smaller ratios have poor conjugate tooth geometry. This is the minimum necessary to gain the resolution and damping benefits without adding unnecessary housing mass.

---

### 1f. Vibration Mitigation Strategy

**Decision**: Implement a tiered vibration mitigation strategy across all cycloidal drives.

**Why is vibration a concern?** Each cycloidal drive's eccentric cam (a 608ZZ bearing offset ~1mm from the motor shaft centreline) creates a rotating centrifugal imbalance force $F = m \cdot e \cdot \omega^2$. At 600 RPM motor input, this is ~79 mN per drive. With 4 drives on the arm, unmitigated vibration accumulates and is amplified at the end-effector.

**Mitigation decisions (in priority order):**

| Measure | Implementation | Cost | Joints |
|:---|:---|:---:|:---|
| **Counterweight disk** | Second 608ZZ at 180° on rear motor shaft | ~$2/joint | J1–J4 (mandatory) |
| **Twin-disk cycloidal** | Two disks 180° out of phase; cancels torque ripple | Doubles disk print time | J1, J2 (high duty cycle) |
| **S-curve trajectories** | MoveIt 2 jerk-limited profiles (`joint_limits.yaml`) | Software only | All joints |
| **1/32 microstepping** | CL42T DIP switch (J3/J4); CL57T already supports | No cost | J3, J4 |
| **PTFE grease** | Standard lubrication requirement | Already in BOM | J1–J4 |

**Rationale**: The counterweight is the most impactful and cheapest fix — it statically balances the rotating assembly and eliminates the imbalance force at **all speeds**. The twin-disk addition at J1/J2 addresses torque ripple, which is a secondary vibration source distinct from the imbalance. S-curves prevent the firmware from exciting the estimated 18.6 Hz PETG link resonance during acceleration phases. Together, these measures should reduce vibration to a level imperceptible during normal pick-and-place.

---

### 1g. PETG over PLA or ABS

**Decision**: Use **PETG filament** as the primary structural material.

**Rationale**:
- **vs. PLA**: PLA has a glass transition temperature of ~60°C. A stepper motor running at 50% duty cycle in an enclosure can heat motor mounts to 55–70°C, causing PLA to soften and deform under load. PETG's 80°C Tg provides safe headroom.
- **vs. ABS**: ABS warps severely during printing (requires enclosure, specific bed temperatures) and releases unpleasant fumes. PETG prints reliably on an open printer with a PEI-coated bed.
- **vs. ASA/Nylon**: Stronger materials, but require specialized hardware; PETG is optimal for the shop-printable constraint.

---

## 2. Electronics & Control

### 2a. Closed-Loop Stepper Kits (CL57T / CL42T) over Open-Loop

**Decision**: Use **integrated closed-loop stepper kits** for J1–J4 instead of open-loop drivers (TB6600, A4988, etc.).

**Alternatives Considered**:

| Option | Pros | Cons |
|:---|:---|:---|
| Open-loop steppers | Cheap, simple | Skip steps under load → arm loses position without knowing |
| Open-loop + separate AS5600 encoder | Position monitoring | STM32 must implement full correction loop; complexity |
| **Closed-loop kit (CL57T/CL42T)** | Encoder+correction built into driver IC | Costs ~2–3× more than an open-loop driver |
| Servo motors (Dynamixel) | Very capable, compact | Expensive ($50–$200 per joint), proprietary protocol |

**Rationale**: The CL57T and CL42T drivers perform closed-loop correction **within the driver itself** — if the motor skips a step, the driver detects the encoder mismatch and corrects it without any STM32 involvement. This dramatically simplifies firmware and eliminates missed-step failures, which are the #1 reliability problem with open-loop stepper arms. The cost premium over TB6600 drivers is ~$40 per joint — well worth it for a reliable, repeatable arm.

---

### 2b. STM32 + Raspberry Pi Hierarchy over Single-Board Solution

**Decision**: Use a **two-tier compute architecture** (STM32 for real-time, RPi 4 for planning) rather than trying to do everything on one device.

**Why not Raspberry Pi alone?**
Linux is not a real-time OS. Even with `PREEMPT_RT` patches, the Pi's scheduler can introduce millisecond-scale jitter in motor control loops. Stepper motors require microsecond-precise pulse timing. A 1ms timing jitter causes audible vibration and velocity ripple.

**Why not Arduino/ESP32 alone?**
An Arduino Mega or ESP32 can generate precise step pulses, but has insufficient RAM and compute to run ROS 2, trajectory planning, or IK solving. The ESP32's RTOS is capable, but the software ecosystem (ROS 2, MoveIt) is built for Linux.

**Conclusion**: The STM32 handles microsecond-level timing in hardware (no OS, hardware timers), while the Pi handles the math-heavy planning layer in software. This is the same architecture used by professional robot arms (e.g., the UR5 uses a dedicated FPGA + a PC for this split).

---

### 2c. 74HC245 Logic Level Shifter (Not Resistor Divider)

**Decision**: Use the **74HC245 octal bus transceiver** for 3.3V → 5V level shifting, not a simple resistor voltage divider.

**Rationale**: A resistor divider (e.g., 1kΩ/2kΩ) works for **downward** shifting (5V → 3.3V). For upward shifting (3.3V → 5V), a resistor divider cannot amplify voltage — you need an active buffer. The 74HC245 has a propagation delay of ~8ns, well within the STM32's minimum STEP pulse width. It handles all 8 STEP/DIR signals simultaneously for just ~$3.

---

### 2d. Mean Well LRS-350-24 PSU (Not 24V Laptop Adapter)

**Decision**: Use the **Mean Well LRS-350-24** industrial enclosed switching PSU, not a commodity 24V adapter.

**Rationale**:
- Laptop-style 24V adapters typically max out at 3–5A — insufficient for the 13.8A peak requirement
- The LRS series has proper **EMI filtering** — critical for preventing motor switching noise from propagating back into the logic supply and corrupting I2C encoder reads
- The **IEC C14 panel connector** allows a proper fused inlet with an E-stop in the AC line — critical for safe operation
- Mean Well has published MTBF figures and certifications; unbranded adapters do not

---

## 3. Software Architecture

### 3a. ROS 2 (Humble) over Custom Communication Protocol

**Decision**: Use **ROS 2 with MoveIt 2** for all high-level control, rather than writing a custom control stack.

**Rationale**: The ROS 2 ecosystem provides:
- **MoveIt 2**: Battle-tested motion planning with OMPL, collision avoidance, and IK solvers
- **`ros2_control`**: A standardized hardware abstraction layer — swap simulation/real hardware by changing one parameter
- **`robot_state_publisher`**: Automatic URDF-based transform tree for RViz and collision checking
- **Gazebo integration**: The simulation stack plugs directly into the control stack with no code changes

Writing a custom equivalent would take months and would lack the testing coverage of industry-standard packages.

**Trade-off**: ROS 2 on a Raspberry Pi remains computationally heavy. Running in Docker adds overhead. The **Pi 4** improves headroom over older Pi generations for MoveIt / planning; if latency becomes an issue, migrating to a Pi 5 or a small x86 NUC is straightforward — the ROS 2 code is identical.

---

### 3b. Docker for ROS 2 Deployment

**Decision**: Run all ROS 2 nodes in **Docker containers** managed by `docker-compose`.

**Rationale**:
- ROS 2 Humble requires Ubuntu 22.04. The Pi may run a different OS version for other tasks — Docker keeps the ROS environment isolated.
- The `docker-compose.yml` file is a single source of truth for the entire software environment, making setup reproducible from a fresh SD card in minutes.
- Container volumes mount the `/software/` directory, so code changes are reflected immediately without rebuilding the image.

---

### 2e. Joint Node Links: RS-485 Control + Optional Wi-Fi Service (Not Wi-Fi Motion)

**Decision**: Each ESP32 joint node uses **RS-485** as the **only** path for motion, homing, enable, and watchdog traffic to/from the STM32 bus master. **Wi-Fi** (ESP32-C3 built-in) is **optional** and used **only** in a dedicated **service mode** for configuration, logs, and OTA — **Wi-Fi is off or logically disabled during motion**.

**Alternatives considered**:

| Option | Pros | Cons |
|:---|:---|:---|
| **Wi-Fi / BLE only** (Pi talks to all nodes wirelessly) | No RS-485 harness | Jitter, dropouts, EMI on metal arm, higher idle current, weak safety story |
| **RS-485 only** (no Wi-Fi) | Simplest RF | OTA and per-node config require USB serial at each link |
| **RS-485 + optional Wi-Fi service** (chosen) | Reliable control; convenient bench tooling | Two stacks to maintain; must enforce mode separation in firmware |

**Rationale**: The arm already needs a differential bus for deterministic multi-drop control near motor EMI. Wi-Fi is still useful for human-facing tasks (flash firmware, set `NODE_ID`, read logs) without betting homing or MoveIt streaming on a 2.4 GHz link. Full policy: [`implementation/joint_node_connectivity.md`](implementation/joint_node_connectivity.md).

---

## 4. Decisions Deferred (TBD)

| Decision | Options | Blocking Factor |
|:---|:---|:---|
| Wrist encoder (AS5600 on J5/J6) | Add or skip | Test open-loop accuracy first; add if drift is a problem |
| Collision avoidance method | OctoMap (camera) vs. static scene | Camera integration TBD |
| User interface | Web dashboard vs. RViz markers vs. joystick | Depends on final workflow preference |
| Gripper type | Parallel jaw vs. vacuum vs. magnetic | Depends on target objects for pick-and-place |
| J4 ratio refinement | Stay at 10:1 or reduce to 8:1 | Depends on measured CAD mass — smaller ratio = lighter housing |

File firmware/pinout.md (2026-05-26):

# STM32F401RE Pinout Decisions

This document tracks the pin assignment strategy for the STM32F401RE firmware target.

**Board alignment:** Matches `platformio.ini`: **Nucleo-F401RE** (`board = nucleo_f401re`).
It is intentionally a design note, not a generated CubeMX file.
The current firmware code is still a scaffold, so the final pin map should be reviewed
again before hardware bring-up.

## Why This Exists

The STM32F401RE has many multifunction pins, but only a subset can be used at the same
height of the design without conflicts. The important part is not just "what pins exist",
but which peripheral functions must be reserved together:

- SWD debug/programming pins must stay available.
- The host communication link needs a stable UART or USB path.
- Encoder feedback needs a clean I2C bus.
- Six stepper axes need six STEP outputs and six DIR outputs.
- Homing, fault, and emergency-stop signals can quickly consume the remaining GPIO.

That means the pinout should be planned as a budget, not as a collection of isolated pins.

## Current Firmware State

The code in `stm32_core/src/main.cpp` is still a single-axis prototype.
It currently uses placeholder Arduino-style pin definitions and a single AS5600 encoder.
The real multi-axis firmware will likely move the pin assignments into a central header
or board-specific configuration file so that all drivers share one source of truth.

## Design Rules

### 1. Reserve the essential system pins first

These pins should not be repurposed for robot I/O:

- `PA13` / `PA14`: SWDIO and SWCLK for programming and debug
- `NRST`: reset line
- `BOOT0`: boot mode strap

If a board variant exposes a user button or LED on a shared pin, confirm it does not
interfere with the intended robot functions.

### 2. Keep host communication separate from debug

The robot link to the Raspberry Pi should not depend on the same interface used for flashing
or console output unless that is a deliberate choice.
For this project, the preferred pattern is:

- One UART for the robot control link
- SWD kept for programming/debugging
- Optional secondary debug console only if there are enough free pins

This keeps the motion-control path independent of local development convenience.

### 3. Reserve one I2C bus for optional wrist feedback

J1–J4 use closed-loop driver kits whose factory motor encoder is read **inside the driver**; the STM32 never touches I2C for those joints. The shared I2C bus on this design only matters for the **optional** AS5600 add-on at J5 / J6.

Recommended bus selection (kept reserved even when no AS5600 is fitted, so a Phase 2 retrofit is a wiring change rather than a firmware redesign):

- `I2C1` on `PB6` (SCL) and `PB7` (SDA)

Reasons:

- Common on STM32F4 boards
- Easy to route
- Leaves the higher-value pins free for time-critical signals
- A TCA9548A multiplexer is only required if **both** J5 and J6 get an AS5600 (since both share the fixed `0x36` address). With one wrist encoder, the AS5600 sits directly on the bus.

### 4. Keep STEP/DIR pins on plain GPIO unless hardware timers are proven necessary

The current firmware scaffold uses software-stepped motion control.
That means the stepper outputs only need reliable digital outputs for now.
If the design later migrates to timer-driven pulse generation, the pin map should be
rechecked against timer-capable alternate functions.

## Proposed Pin Budget

The table below is the working allocation strategy.
Some entries are firm, and others are still candidates because the final joint count and
fault strategy may change.

| Function | Count | Suggested STM32F401RE Resource | Status |
| --- | ---: | --- | --- |
| SWD debug/programming | 2 | `PA13`, `PA14` | Reserved |
| Host control link | 2 | `USART1` or equivalent external UART | Needed |
| Encoder bus | 2 | `I2C1` on `PB6`, `PB7` | Preferred |
| Step outputs | 6 | Six GPIO outputs | Needed |
| Direction outputs | 6 | Six GPIO outputs | Needed |
| Home sensors | 6 | Six interrupt-capable inputs | Needed |
| Driver alarms | 6 | Six fault inputs, or a grouped fault line | Open |
| E-stop | 1 | Dedicated interrupt input | Needed |
| Spare expansion | 1+ | GPIO or I2C expander | Strongly recommended |

## Recommended Functional Grouping

### Motion outputs

Use one GPIO pair per joint:

- J1: STEP + DIR
- J2: STEP + DIR
- J3: STEP + DIR
- J4: STEP + DIR
- J5: STEP + DIR
- J6: STEP + DIR

This keeps the firmware simple and makes it easy to map each joint to a controller slot.

### Encoder feedback

For J1–J4, position comes from the closed-loop driver itself (RS-485 from the CL57T / CL42T) — no STM32 GPIO is consumed by the driver-side encoder. For J5 / J6, the optional wrist AS5600 (if fitted) lives on `I2C1`. A TCA9548A multiplexer is needed only when both wrist AS5600 boards are populated, since they share the fixed `0x36` address.

### Fault handling

The most likely place for pin pressure is fault handling.
If every driver has its own ALARM line plus a separate home sensor, the board can run out of
clean GPIO faster than expected.
Two practical options exist:

1. Keep each fault line discrete and use more of the GPIO budget.
2. Group less critical faults through an I2C GPIO expander or a wired-OR fault bus.

The second option is usually the safer choice if the board variant proves tight.

## Candidate Board-Level Allocation

This is a practical starting point for review, not a final electrical drawing.
It favors keeping the high-value buses on stable pins and spreading the stepper outputs
across available GPIO banks.

| Signal Group | Candidate Pins | Notes |
| --- | --- | --- |
| SWD | `PA13`, `PA14` | Do not use for robot I/O |
| Robot UART | `PA9`, `PA10` | Good candidate for the Pi link if available |
| I2C1 | `PB6`, `PB7` | Encoder bus |
| J1 STEP/DIR | `PB0`, `PB1` | General GPIO |
| J2 STEP/DIR | `PB10`, `PB11` | General GPIO |
| J3 STEP/DIR | `PB12`, `PB13` | General GPIO |
| J4 STEP/DIR | `PB14`, `PB15` | General GPIO |
| J5 STEP/DIR | `PC6`, `PC7` | General GPIO |
| J6 STEP/DIR | `PC8`, `PC9` | General GPIO |

This layout keeps the core buses separate from the motion outputs and leaves the lower
GPIO range available for sensors and fault inputs.
The exact pin numbers should still be checked against the specific package and board variant
before hardware wiring is finalized.

## Open Decisions

- Whether the host link should use UART or USB CDC
- Whether each motor driver needs its own alarm input or a shared fault line is enough
- **Distributed (production):** Hall homing inputs are on each **ESP32 joint node** (`joint_node/src/pinout.h`), not on the Nucleo — see [`docs/implementation/distributed_bus_architecture.md`](../docs/implementation/distributed_bus_architecture.md)
- **Centralized (bench only):** whether six homing sensors tie to STM32 GPIO or an I2C GPIO expander
- Whether the final firmware uses Arduino-style GPIO control or STM32 HAL/CubeMX configuration
- Whether a board-specific `pinout.h` should be introduced once the final map is settled

## Recommendation

For now, treat this as the working pinout policy:

- Reserve SWD and reset pins permanently.
- Put the Pi link on one UART.
- Put all encoders on one I2C bus.
- Give each joint a dedicated STEP/DIR pair.
- Use the remaining GPIO for homes, alarms, and E-stop.
- Add an I2C GPIO expander if the board runs out of clean interrupt-capable inputs.

That approach fits the STM32F401RE resource limits without overcommitting the design too early.

---

## RS-485 bus master (distributed architecture)

When using ESP32 joint nodes ([`docs/implementation/distributed_bus_architecture.md`](../docs/implementation/distributed_bus_architecture.md)), the Nucleo acts as the **RS-485 master** only — it no longer bit-bangs STEP/DIR for remote joints.

| Function | Pin | Nucleo label | Notes |
|:---|:---|:---|:---|
| `RS485_TX` | `PA9` (`USART1_TX`) | **D8** | To MAX485 `DI` — Arduino header (M-F dupont) |
| `RS485_RX` | `PA10` (`USART1_RX`) | **D2** | From MAX485 `RO` |
| `RS485_DE` | `PA4` | **A2** | HIGH = transmit; tie `/RE` to `DE` if separate |
| USB debug `Serial` | `PA2` / `PA3` (`USART2`) | — | ST-Link VCP — do not use for RS-485 |
| Pi `UART_TX/RX` | (future) | — | Production may move host UART off `PA9`/`PA10` |

**Termination:** 120 Ω at the Nucleo transceiver (bus end). Second terminator at the gripper node.

Joint-node GPIO (STEP/DIR/ENABLE/ALARM/HOME) lives in [`joint_node/src/pinout.h`](joint_node/src/pinout.h).

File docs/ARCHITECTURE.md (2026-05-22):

# Architecture index

One-page map into the design documentation. The repository is a **monorepo** spanning
mechanical CAD, electrical design, STM32 firmware, ROS 2 software, Python simulation,
and (planned) Simulink model-based design.

## System context

| Layer | Location | Role |
|---|---|---|
| Planning / orchestration | `software/ros2_ws/` | ROS 2 Humble, MoveIt 2, hardware bridge |
| Real-time control | `firmware/stm32_core/`, `firmware/joint_node/` | STM32 bus master + Pi UART; ESP32 per-joint STEP/DIR, Hall homing |
| Digital twin | `simulation/` | Python kinematics, URDF, Renode firmware smoke |
| Mechanical | `mechanical/` | SolidWorks models; STEP exports where present |
| Electrical | `hardware/kicad/`, `hardware/wireviz/` | Schematics, harness diagrams |
| Model-based design (planned) | `simulink/` | README scaffold only — not in tree yet |

**High-level story:** [`Application.md`](Application.md) · [`Design_Choices.md`](Design_Choices.md) · [`Scope.md`](Scope.md)

## Implementation deep dives

| Topic | Document |
|---|---|
| Firmware (STM32, ESP32 nodes, protocol) | [`implementation/firmware_architecture.md`](implementation/firmware_architecture.md) |
| Distributed RS-485 bus + homing | [`implementation/distributed_bus_architecture.md`](implementation/distributed_bus_architecture.md) |
| RS-485 control + optional Wi-Fi service | [`implementation/joint_node_connectivity.md`](implementation/joint_node_connectivity.md) |
| Software (ROS 2, bridge, MoveIt) | [`implementation/software_architecture.md`](implementation/software_architecture.md) |
| Simulation & Gazebo | [`implementation/simulation_environment.md`](implementation/simulation_environment.md) |
| Simulink workflow (planned) | [`implementation/simulink_workflow.md`](implementation/simulink_workflow.md) |
| Mechanical design | [`implementation/mechanical_design.md`](implementation/mechanical_design.md) |
| Electrical / KiCad | [`implementation/electrical_design.md`](implementation/electrical_design.md) |

## Build & verify

- Setup: [`../scripts/setup.sh`](../scripts/setup.sh)
- Tests: [`../TESTING.md`](../TESTING.md)
## Subsystem READMEs

- [`../firmware/README.md`](../firmware/README.md)
- [`../software/README.md`](../software/README.md)
- [`../simulation/renode/README.md`](../simulation/renode/README.md)
- [`../simulink/README.md`](../simulink/README.md) (scaffold)

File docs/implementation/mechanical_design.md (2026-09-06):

# Mechanical Design & Kinematics

<!--
This document details the mechanical architecture, actuator selection, power transmission strategy,
structural materials, and kinematic approach for the 6-DOF robot arm.
-->

## 1. Design Goals & Payload Estimate

The arm is designed for **desktop-scale pick-and-place operations**, targeting an estimated payload of **0.5 – 1.0 kg** at the end-effector. The total arm reach is targeted at **~500mm** (from shoulder to wrist) based on the link-length breakdown below. These targets will be validated in simulation before final hardware procurement.

**Gear-ratio authority.** Firmware uses `kJ1MotorRevsPerJointRev = 19.0F` and `kJ2MotorRevsPerJointRev = 15.0F` in `firmware/stm32_core/lib/drivers/src/stepper_driver.cpp`. Physical pin/lobe counts are `[NEEDS MEASUREMENT]`. Effective-output-torque products that assumed twenty-to-one reduction are superseded.

---

## 2. Actuator Selection

The motor stack is split into three tiers based on joint position and torque requirement. Mounting heavier motors closer to the base is a deliberate strategy to minimize the **moving moment of inertia** — the further mass sits from the base pivot, the more energy is wasted just swinging the arm itself.

| Joint | Description | Motor | Driver | Torque | Gearing | Eff. Output Torque |
|:---|:---|:---|:---|:---|:---|:---|
| J1 | Base Rotation | NEMA 23 (2.0 Nm) | CL57T Closed-Loop | 2.0 Nm | Cycloidal 19:1 (firmware) | `[NEEDS MEASUREMENT]` |
| J2 | Shoulder Pitch | NEMA 23 (2.0 Nm) | CL57T Closed-Loop | 2.0 Nm | Cycloidal 15:1 (firmware) | `[NEEDS MEASUREMENT]` |
| J3 | Elbow Pitch | NEMA 17 (80 Ncm) | CL42T Closed-Loop | 0.80 Nm | Cycloidal 15:1 | **~12 Nm** |
| J4 | Forearm Twist | NEMA 17 (42 Ncm) | CL42T Closed-Loop | 0.42 Nm | Cycloidal 10:1 | **~4.2 Nm** |
| J5 | Wrist Pitch | NEMA 14 (14 Ncm) | TMC2209 Open-Loop | 0.14 Nm | Direct | **0.14 Nm** |
| J6 | Tool Roll | NEMA 14 (14 Ncm) | TMC2209 Open-Loop | 0.14 Nm | Direct | **0.14 Nm** |

> **Note on Closed-Loop Kits**: J1–J4 use integrated closed-loop stepper kits (`1-CL57T-S20-V41` for J1/J2, `1-CL42T-S08-V41` for J3, `1-CL42T-S04-V41` for J4) which include the motor, matched driver, and encoder wiring. The built-in encoder closes the loop at the driver level — no external AS5600 required on these joints.

---

## 3. Gearing & Power Transmission

All four driven joints (J1–J4) use **cycloidal drives**. This eliminates the torque shortfall that belt-only drives had at J3, unifies the manufacturing process (same print profiles, same components), and removes belt-stretch as a source of positional error.

### 3a. Cycloidal Drive Design (All J1–J4)

A cycloidal drive is a compact, high-ratio speed reducer that achieves a large gear ratio in a single short stage. Its key properties:
- **3D Printable**: Ring pins are hardened steel dowel pins (3–5mm); the disk and housing are PETG. No metal machining.
- **High Ratio in Compact Form**: 10:1–30:1 in a package shorter than the motor itself.
- **Near-Zero Backlash**: The disk is always in contact with multiple pins simultaneously — no gear mesh "slop".
- **Load Shared Across Many Pins**: Force is distributed across ~half the pins at any moment, drastically reducing peak contact stress vs. a single-tooth mesh.

**Ratio selection per joint** (CAD intent, not counted on hardware). Firmware J1/J2 constants are 19.0 and 15.0; physical `[NEEDS MEASUREMENT]`.

| Joint | Pins (N) CAD intent | Disk Lobes (N-1) CAD intent | Ratio in controller | Rationale |
|:---:|:---:|:---:|:---:|:---|
| J1 | `[NEEDS MEASUREMENT]` | `[NEEDS MEASUREMENT]` | 19:1 firmware | Highest torque demand |
| J2 | `[NEEDS MEASUREMENT]` | `[NEEDS MEASUREMENT]` | 15:1 firmware | Not identical to J1 in firmware; do not assume a shared housing ratio |
| J3 | 15 | 14 | 15:1 | Resolves belt shortfall; smaller housing fits NEMA 17 envelope |
| J4 | 10 | 9 | 10:1 | Low torque demand; smallest housing, minimizes added mass |

**Key Components (per drive unit):**
- **Eccentric cam**: One `608ZZ` bearing press-fit onto the motor shaft, offset by **1.0 mm** from centre
- **Counterweight disk**: A second `608ZZ` (or equivalent mass) press-fit on the rear shaft at 180° offset — cancels eccentric imbalance and reduces vibration (see §3c)
- **Cycloidal disk**: 3D-printed PETG with epitrochoidal tooth profile; toleranced at +0.1 to +0.15 mm clearance to ring pins
- **Ring gear pins**: Hardened steel M4 dowel pins (4mm ⌀) press-fit into the housing — they cannot shear; only the disk is consumable
- **Output bearings**: `6806` or `6808` thin-section bearings at J1/J2; `6804` or `6806` at J3/J4 (smaller motor, smaller housing)
- **Output pin carrier**: A second set of output pins (same M4 dowels) in the output flange that engage the drive holes in the cycloidal disk — transmit rotation without transmitting the eccentric motion

> **Lubrication is mandatory**: Pack synthetic PTFE grease into every cycloidal assembly before first use. Dry running will melt and destroy the PETG disk within minutes of sustained load.

---

### 3b. Vibration in Cycloidal Drives & Mitigation

The rotating eccentric cam creates a **centrifugal imbalance force** that, if unmitigated, causes the whole arm to vibrate — particularly at J3 and J4 which are cantilevered further from the base.

#### Source of Vibration

The eccentric cam assembly (608ZZ bearing, ~20g, offset 1.0 mm from the shaft centreline) acts as an unbalanced rotating mass:

$$F_{imbalance} = m_{ecc} \times e \times \omega^2$$

- At **300 RPM** → ω = 31.4 rad/s → F ≈ **20 mN** (negligible)
- At **1000 RPM** → ω = 104.7 rad/s → F ≈ **220 mN** (noticeable, especially at end-effector)
- At **2000 RPM** → ω = 209.4 rad/s → F ≈ **880 mN** (significant — unacceptable for precision tasks)

High motor speeds on the *input* side of a high-ratio cycloidal drive are common (output moves slowly, but motor spins fast). Normal operational input speeds of 300–600 RPM are expected for smooth trajectories. RPM at the firmware J1/J2 ratios for a given output rate is `[NEEDS MEASUREMENT]`.

#### Mitigation Strategies (Priority Order)

1. **Counterweight Disk (Mandatory)**: A second bearing or custom-machined/printed disk of matching mass is mounted on the **rear** of the motor shaft, diametrically opposite (180° offset from) the eccentric cam. This statically balances the rotating assembly, eliminating the imbalance force entirely at all speeds. **Must be implemented on all four cycloidal drives.**

2. **Twin-Disk (Dual-Phase) Cycloidal (Strongly Recommended for J1/J2)**: Use two cycloidal disks stacked axially, keyed 180° out of phase on the same eccentric. Their eccentric forces cancel each other continuously. This also doubles the load capacity and smooths the torque ripple from the individual disk lobes engaging pins. J1 and J2 should use this design given their higher duty cycles and the fact that any base vibration is amplified up the full arm length.

3. **S-Curve Velocity Profiles (Software — Mandatory)**: MoveIt 2 trajectory parameterization must use **S-curve** (jerk-limited) profiles rather than trapezoidal profiles. Trapezoidal profiles produce instantaneous acceleration changes that stimulate resonant modes of the cycloidal drive and PETG links. S-curves limit the rate of change of acceleration (jerk), preventing resonance excitation. Configure in `ompl_planning.yaml` and the `joint_limits.yaml` jerk parameters.

4. **Microstepping (1/32 or Higher)**: Higher microstepping reduces the per-step torque impulse from the stepper motor. Each individual step is smaller, reducing the amplitude of periodic forcing at the stepping frequency. The CL42T and CL57T support up to 1/256 microstepping — the default of 1/16 is a minimum; 1/32 is recommended for J3/J4.

5. **PTFE Grease (Mandatory, also Dampens)**: A well-greased cycloidal drive is significantly quieter and more vibration-damped than a dry one. The grease film between the disk and ring pins acts as a viscous damper that absorbs high-frequency vibration energy.

---

## 4. Structural Materials & Manufacturing

### 4a. Primary Structure: 3D-Printed PETG
PETG is chosen over PLA or ABS for the following reasons:

| Property | PLA | PETG | ABS |
|:---|:---|:---|:---|
| Glass Transition Temp | ~60°C | **~80°C** | ~100°C |
| Layer Adhesion | Good | **Excellent** | Fair |
| Warp Resistance | Good | **Excellent** | Poor |
| Impact Resistance | Brittle | **Good flex** | Good |
| Post-print difficulty | Easy | **Easy** | Hard (fumes, warp) |

Motors generate significant heat. PETG's 80°C glass transition temperature provides headroom that PLA simply does not.

### 4b. Fasteners & Inserts
- **M3 / M4 / M5 Alloy Steel Bolts & Nuts**: Standard metric hardware for all structural connections
- **M3×5mm Brass Heat-Set Inserts**: Press-in with a soldering iron; creates a permanent metallic threaded boss inside PETG that withstands high-torque motor mounting without stripping
- **Blue Loctite**: Applied to all motor mount fasteners to prevent vibration-induced loosening

### 4c. Bearings
- **J1/J2 Output (Cycloidal)**: `6806` or `6808` thin-section bearing — carries the full structural (axial bending) load at the base and shoulder joints
- **J3/J4 Output (Cycloidal)**: `6804` or `6806` thin-section bearing — appropriate for the smaller NEMA 17 housing profile
- **Eccentric Cam (All Cycloidal)**: `608ZZ` bearings — one per disk stage as the eccentric cam rolling element
- **Counterweight (All Cycloidal)**: Second `608ZZ` (or printed mass) on the rear motor shaft, 180° offset from the eccentric cam
- **Motor shafts must NEVER carry structural loads** — motor shafts are only coupled for torque transmission. All bending/axial forces must pass through the output bearing.

---

## 5. End-Effector

The end-effector is a self-contained sub-assembly that bolts to the **J6 tool flange**. It is mechanically and electrically independent from the joint motors, which keeps tool changes from disturbing the arm wiring.

- **Gripper Actuator — `MG996R` metal-gear micro servo**.
  - **Mounting**: inside the gripper body itself (3D-printed claw / parallel-jaw assembly) that bolts to the J6 tool flange. The MG996R is **not** mounted in the arm wrist — J6 already has its own NEMA 14 stepper for tool roll. The gripper servo only opens / closes the jaws.
  - **Power**: dedicated `5V_SERVO` rail from a third LM2596 buck off `24V_MOTOR` (see [electrical_design.md §1b](electrical_design.md)). It is **not** sharing the `5V_LOGIC` or `5V_PI` rails — stall spikes from the servo would otherwise glitch the MCU.
  - **Signal**: a single ~50 Hz PWM line from one STM32 timer pin (e.g. `PA8 / TIM1_CH1`). 3.3 V drive is sufficient for a hobby servo's high-impedance signal pin, so no level shifter is required.
  - **Wiring across the wrist**: all EOAT signals (`5V_SERVO`, `GND_M`, `PWM`, optional `FSR`) cross the wrist on a single 4-pin tool-flange connector. See [`hardware/wireviz/60_end_effector.yml`](../../hardware/wireviz/60_end_effector.yml).
- **Optional Force Feedback**: a **Force Sensitive Resistor (FSR)** on the gripper fingertip pad, fed through a 10k voltage divider into a STM32 ADC pin. Enables a grip-force PID to prevent crushing delicate objects. Also lives inside the gripper body, not the arm.

---

## 6. Denavit-Hartenberg (DH) Parameters

The arm's kinematics are parameterized using the **Modified DH convention**. These parameters define the geometric relationship between each consecutive joint frame and are used directly in both the Python IK/FK solver and the URDF model.

| Joint | a (mm) | α (deg) | d (mm) | θ (variable) | Notes |
|:---:|:---:|:---:|:---:|:---:|:---|
| J1 | 0 | 90 | d1 | θ1 | Base rotation; d1 = height of base |
| J2 | L1 | 0 | 0 | θ2 | Shoulder pitch; L1 = upper arm length |
| J3 | L2 | 90 | 0 | θ3 | Elbow pitch; L2 = forearm length |
| J4 | 0 | -90 | d4 | θ4 | Forearm twist |
| J5 | 0 | 90 | 0 | θ5 | Wrist pitch |
| J6 | 0 | 0 | d6 | θ6 | Tool roll; d6 = flange offset |

> **L1, L2, d1, d4, d6** are physical link lengths determined by the CAD model. These will be updated once the first prototype joints are dimensioned.

---

## 7. Source CAD & export workflow

Authoritative mechanical CAD is in **`mechanical/sw-models/`** (SolidWorks). To keep the repo and reviews usable (without relying on Windows-only binary formats alone), see **[CAD source files & export conventions](cad_exports.md)** for which formats to export per part, assembly, and drawing, and how to name them.

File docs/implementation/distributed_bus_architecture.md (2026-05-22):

# Distributed Bus Architecture (RS-485 + ESP32 Joint Nodes)

The arm moves from a **centralized** control box (one STM32, long STEP/DIR harnesses) to **distributed joint nodes**: a small **ESP32** next to each motor driver, daisy-chained on a **4-conductor** link through the links.

| Pair | Signals | Purpose |
|:---|:---|:---|
| **A** | `RS485_A`, `RS485_B` | Half-duplex differential bus (twisted pair) |
| **B** | `24V_MOTOR`, `GND_M` | Motor rail + return (gauge per segment current) |

Logic 5V/3.3V is **buck-converted locally** at each node from `24V_MOTOR` (not passed on the 4-wire harness).

---

## Why RS-485 (not CAN)

| Criterion | RS-485 | CAN 2.0 |
|:---|:---|:---|
| ESP32 integration | UART + MAX3485 + DE pin | TWAI peripheral (no extra controller on many boards) |
| Driver ecosystem | CL57T already exposes RS-485 for telemetry | Would not reuse driver UART without adapters |
| Harness | 2-wire differential + termination at ends | Same |
| Software cost | Master-scheduled polling (simple) | Hardware arbitration (slightly more complex frames) |

**Decision:** **RS-485 @ 921600 baud**, master-slave polling from the base **STM32 Nucleo**.

**Also decided:** ESP32 joint nodes may use **Wi-Fi only as an optional service channel** (config, logs, OTA) — **disabled during motion**. See [`joint_node_connectivity.md`](joint_node_connectivity.md).

---

## Topology

```text
[Raspberry Pi] --UART--> [STM32 master @ base] --RS-485-->
      J1 node --> J2 node --> J3 --> J4 --> J5 --> J6 --> Gripper node
      (each: ESP32 + driver + motor phases local)
```

- **Daisy chain:** `BUS_IN` / `BUS_OUT` + `PWR_IN` / `PWR_OUT` on each joint PCB.
- **Termination:** 120 Ω between A/B at the **base master** and at the **last node** (gripper/wrist) only.
- **Rotation (J1):** The same 4 conductors pass through the base swivel or slip ring; bus width stays fixed.

---

## Node map

| Node ID | Role | Motor / actuator |
|:---:|:---|:---|
| `1` | J1 | NEMA 23 + CL57T |
| `2` | J2 | NEMA 23 + CL57T |
| `3` | J3 | NEMA 17 + CL42T |
| `4` | J4 | NEMA 17 + CL42T |
| `5` | J5 | NEMA 14 + TMC2209 |
| `6` | J6 | NEMA 14 + TMC2209 |
| `7` | Gripper | MG996R (PWM) |
| `0` | Master | STM32 (not on bus as a slave) |
| `0xFF` | Broadcast | Heartbeat / discovery |

---

## Frame format

Implemented in [`firmware/lib/bus_protocol/`](../../firmware/lib/bus_protocol/).

```text
[0xAA][0x55][DST][SRC][CMD][LEN][PAYLOAD...][CRC16_LE]
```

- **CRC16-CCITT** over `DST` through end of payload (poly `0x1021`, init `0xFFFF`).
- **Max payload:** 32 bytes. **Max frame:** 40 bytes.

### Command IDs

| CMD | Name | Direction | Payload |
|:---:|:---|:---|:---|
| `0x20` | `SET_JOINT_TARGET` | Master → joint | `position_deg` (f32), `velocity_deg_s` (f32) |
| `0x21` | `JOINT_STATE` | Joint → master | `position_deg`, `velocity_deg_s`, `fault_flags` (u8) |
| `0x22` | `ENABLE` | Master → node | `u8` 1=on, 0=off |
| `0x23` | `HOME` | Master → joint | empty — starts **autonomous homing** on that node (see § Homing) |
| `0x24` | `HEARTBEAT` | Master → broadcast | empty |
| `0x25` | `SET_GRIPPER` | Master → gripper | `duty` f32 (0=open, 1=closed) |
| `0x26` | `GRIPPER_STATE` | Gripper → master | `duty`, `fault_flags` |

Pi ↔ STM32 **UART packets** (`protocol/packet_codec`, `0x10`/`0x11`) are unchanged in role: the Pi still talks only to the base MCU; the STM32 translates to bus transactions.

---

## Homing (Hall sensors on joint nodes)

Homing is **not** executed on the base STM32. Each motor joint has an **A3144 Hall effect sensor** and a fixed magnet at the mechanical zero; the sensor connects to the local **ESP32** (`HOME` GPIO in [`firmware/joint_node/src/pinout.h`](../../firmware/joint_node/src/pinout.h)). The gripper node has no Hall homing — it only reports PWM state.

### Trigger and ownership

| Layer | Role |
|:---|:---|
| **Pi** | Sends `HOME` (`0x04`) on the Pi↔STM32 UART link when the operator or ROS stack requests homing |
| **STM32** | **Orchestrates** only: disables motion commands, issues bus `HOME` (`0x23`) to nodes **in order** J1 → J2 → … → J6 (see [`../Constraints.md §3e`](../Constraints.md)), waits for each node to finish, then replies `HOMED_OK` to the Pi |
| **ESP32 joint node** | **Executes** homing autonomously after a valid addressed `HOME` frame: STEP/DIR sweep, Hall edge detect, stop, zero local step counter / `position_deg` |

Until homing completes system-wide, the STM32 must reject or ignore absolute position commands (policy in [`firmware_architecture.md`](firmware_architecture.md) §2d).

### Per-node homing FSM (ESP32)

When `HOME` (`0x23`) is received for this node's ID:

1. Assert **ENABLE**, set **DIR** toward the configured “seek home” direction, run **STEP** at a low fixed frequency (profile per joint).
2. Poll **`kHomePin`** (A3144, active-low when the magnet is present).
3. On trigger: stop pulses immediately, latch **position = 0°**, clear velocity, set an internal **homed** flag.
4. Respond on the next master poll with `JOINT_STATE` (position near 0, homed indicated in `fault_flags` or equivalent — TBD in firmware).

If **ALARM** asserts or no **HEARTBEAT** within the watchdog window during homing, the node disables the driver and reports fault.

### Sequence (system)

```text
Pi --HOME--> STM32
                |
                +-- HOME node 1 --> [J1 ESP32: sweep + Hall] --> JOINT_STATE (homed)
                +-- HOME node 2 --> [J2 ESP32: ...]
                ...
                +-- HOME node 6 --> [J6 ESP32: ...]
                |
Pi <--HOMED_OK-- STM32
```

Optional post-home move to a safe **rest pose** is a higher-level policy (STM32 streams `SET_JOINT_TARGET` after all nodes report homed).

---

## Timing and rates

- **Baud:** 921600 (adjust if cable length / EMI requires).
- **Master cycle:** Broadcast heartbeat, then poll nodes `1..7` (request + response each).
- **Target aggregate rate:** ~100–200 Hz full-arm updates; nodes interpolate/set STEP locally between polls.
- **Watchdog:** Each slave disables its driver if no valid `HEARTBEAT` (or addressed command) within **500 ms** (`docs/Constraints.md`).

---

## Firmware layout

| Path | Role |
|:---|:---|
| [`firmware/lib/bus_protocol/`](../../firmware/lib/bus_protocol/) | Shared framing + types (STM32 + ESP32) |
| [`firmware/joint_node/`](../../firmware/joint_node/) | ESP32 slave — **one codebase**, ID via env / NVS / straps |
| [`firmware/stm32_core/lib/bus/`](../../firmware/stm32_core/lib/bus/) | RS-485 master scaffold |
| [`firmware/stm32_core/lib/protocol/`](../../firmware/stm32_core/lib/protocol/) | Pi serial protocol (unchanged semantics) |

### Flashing joint nodes

```bash
cd firmware/joint_node
pio run -e node_j4 -t upload    # production: baked-in ID
pio run -e esp32dev -t upload   # bench: then serial `NODE_ID 4`
```

---

## Hardware notes (per node)

- **RS-485 transceiver:** e.g. MAX3485; **DE** high during TX, low for RX.
- **STEP/DIR/ENABLE/ALARM:** ESP32 GPIO → driver (5 V via level shifter where required).
- **Homing:** A3144 on `HOME` pin → ESP32 GPIO only (not routed to the base harness). Magnet placement defines mechanical zero per link.
- **Gripper node:** Dedicated `5V_SERVO` buck; PWM ~50 Hz on ESP32 LEDC.

Placeholder GPIO map: [`firmware/joint_node/src/pinout.h`](../../firmware/joint_node/src/pinout.h).

---

## Migration from centralized wiring

| Before | After |
|:---|:---|
| 6× STEP/DIR/ENABLE/ALARM to control box | Local to each node |
| Motor phases routed to box | Phases **at joint** (short) |
| STM32 bit-bangs all STEP timers | ESP32 per joint; STM32 schedules bus |
| `20_control_signals.yml` long bundles | `40_bus_harness.yml` (4-conductor daisy) |

Centralized firmware paths remain buildable during bring-up; enable distributed mode when `BusMaster` UART backend is wired.

---

## Open work (scaffold)

- [ ] STM32 `BusMaster::Transaction` UART + DE driver
- [ ] ESP32 STEP/DIR timer loop + homing FSM
- [ ] Gripper LEDC mapping
- [ ] Wireviz + KiCad net names for `RS485_A/B`, daisy connectors
- [ ] `hw_interface` assumes aggregated joint state from STM32 (no Pi bus exposure)
- [ ] Optional Wi-Fi service mode per [`joint_node_connectivity.md`](joint_node_connectivity.md)

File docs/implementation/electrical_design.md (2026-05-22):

# Electrical Design

<!--
This document details the complete electrical architecture:
power system, compute hierarchy, motor drivers, sensors, wiring, and safety systems.
-->

## 1. Power System

### 1a. Main Power Supply — Mean Well LRS-350-24

The selected PSU is the **Mean Well LRS-350-24** (350W, 24V, 14.6A). This choice is driven by the combined peak current draw of all 6 motors:

| Motor | Driver | Peak Current | Count | Subtotal |
|:---|:---|:---|:---:|:---|
| NEMA 23 (2.0 Nm) | CL57T | ~4.0A | 2 | 8.0A |
| NEMA 17 (80 Ncm) | CL42T | ~3.0A | 1 | 3.0A |
| NEMA 17 (42 Ncm) | CL42T | ~2.0A | 1 | 2.0A |
| NEMA 14 (Pancake) | TMC2209 | ~0.4A | 2 | 0.8A |
| **Total (Theoretical Max)** | | | | **~13.8A** |

The LRS-350-24 provides **14.6A**, giving a small but safe margin. Critically, **software motion constraints** are enforced to ensure J1 and J2 (the two highest-current joints) are never both at peak torque simultaneously, keeping the real-world draw well below the PSU limit.

> **Why 24V?** Stepper motor back-EMF scales with RPM. A higher bus voltage allows the driver to force current through the motor windings faster, maintaining torque at higher speeds. Running at 12V would cause torque rolloff at speeds required for smooth arm motion.

### 1b. Logic Power — LM2596 Buck Converters

The 24V rail is **stepped down** to lower voltages for logic components:

| Rail | Voltage | Consumers |
|:---|:---|:---|
| Logic 5V | 5V | 74HC245, Hall sensors; **Nucleo** may take **5 V** from this rail **or** from the ST-Link USB port (never **24 V**) |
| Logic 3.3V | 3.3V | **STM32 core and GPIO** at **3.3 V** — **Nucleo onboard regulator** derives this from the board’s **5 V** (outputs are **~3.3 V**, not 5 V) |
| Pi Power | 5V/≥3A | Raspberry Pi 4 (via dedicated buck converter for isolation; size for peak CPU + USB load) |
| Servo 5V | 5V | MG996R gripper only (third buck or UBEC from `24V_MOTOR`; not shared with logic/Pi rails) |

The LM2596-based buck converter modules are compact and inexpensive. A **separate** buck converter powers the Pi to isolate it from the motor noise on the main logic 5V rail.

**STM32 dev board vs “3.3 V” confusion**: The **microcontroller GPIO** uses **3.3 V logic levels** (a pin driven HIGH is ~3.3 V, not 5 V). The **Nucleo-F401RE** is normally powered from **5 V USB** (ST-Link port) or the board’s 5 V input; the board’s LDO creates **3.3 V** for the STM32 chip. **STEP/DIR from the MCU are therefore 3.3 V signals** — the **74HC245** shifts them to **5 V** for CL57T/CL42T inputs configured for 5 V TTL. Do **not** connect the **24 V motor rail** to any STM32 or Nucleo logic pin.

### 1c. Safety — E-Stop & IEC C14 Inlet

- **E-Stop Button**: Latching mushroom-head button wired **in series** with the PSU's AC input. Pressing it immediately cuts all power to the arm — zero software dependency on safety.
- **IEC C14 Inlet with Fuse**: A panel-mounted C14 connector with an integrated fuseholder. The fuse is sized to the PSU's rated input current as the last-resort overcurrent protection.

---

## 2. Compute Hierarchy

The system uses a **three-tier compute architecture**: planning on the Pi, bus mastering on the base STM32, and **per-joint** real-time control on ESP32 modules next to each driver.

```
[ Raspberry Pi 4 ]          <-- High-Level (ROS 2, MoveIt 2, IK/FK)
        |
    USB / UART
        |
    [ STM32 @ base ]        <-- Bus master, Pi protocol, system safety
        |
    RS-485 (2-wire) + 24V/GND daisy chain through the arm
        |
  [ESP32+driver] x6  +  [ESP32 gripper]
        |
   Motors local to each joint
```

- The **Raspberry Pi 4** runs ROS 2 in Docker containers. It handles trajectory planning, inverse kinematics, and user-facing interfaces. It does **not** perform any real-time motor control.
- The **STM32** at the control box polls joint nodes on **RS-485** (921600 baud) and bridges telemetry/commands to the Pi over UART. See [`distributed_bus_architecture.md`](distributed_bus_architecture.md).
- Each **ESP32 joint node** generates STEP/DIR (or TMC UART) for its local driver, runs homing on the local Hall sensor, and disables the driver on bus watchdog timeout. Optional **Wi-Fi** is for bench service only (off during motion) — [`joint_node_connectivity.md`](joint_node_connectivity.md).

A **legacy centralized** layout (one STM32, all drivers in the box) remains documented in wireviz `20_control_signals.yml` for bring-up; production targets the **4-conductor bus harness** (`hardware/wireviz/35_bus_harness.yml`).

---

## 3. Motor Drivers

### 3a. CL57T — Closed-Loop Driver (J1 & J2, NEMA 23)

The CL57T is a dedicated closed-loop stepper driver. It accepts a STEP/DIR signal from the STM32 and uses the bundled encoder feedback to internally correct for missed steps **without** requiring the STM32 to handle the correction loop. Key settings:

- **Current Range**: 0–8.0A (configured via DIP switches for the 2.0 Nm motor)
- **Input Voltage**: 20–50V DC (24V rail is ideal)
- **Step Resolution**: Configurable from full-step to 1/256 microstepping
- **Alarm Output**: Pulls low on fault (stall, overcurrent) — wired to STM32 interrupt pin

### 3b. CL42T — Closed-Loop Driver (J3 & J4, NEMA 17)

Same closed-loop principle as CL57T but sized for NEMA 17 current ranges:

- **J3** (80 Ncm motor): CL42T configured up to 3.0A
- **J4** (42 Ncm motor): CL42T configured up to 2.0A

### 3c. TMC2209 — Open-Loop Driver (J5 & J6, NEMA 14)

The NEMA 14 wrist motors are driven by TMC2209 modules, the standard for silent, smooth stepper control:

- **StealthChop2**: Near-silent operation at speeds below the threshold (important for lab environment)
- **SpreadCycle**: Falls back to high-efficiency full-power mode for demanding moves
- **Current**: Configured for 0.4A (NEMA 14 rated current) via VREF trimmer or UART
- **No Encoder Required**: The wrist joints carry minimal load, and microstepping resolution at 1/16 or 1/32 is sufficient. If precision becomes an issue, external AS5600 encoders can be added.

### 3d. 74HC245 — Logic Level Shifter

The STM32 outputs **3.3V logic** signals (STEP/DIR). The CL57T and CL42T industrial drivers expect **5V logic** levels. The 74HC245 octal bus transceiver shifts all 3.3V STEP/DIR signals to 5V:

- 1 chip handles 4 signal pairs (8 lines) — one per joint per direction
- Powered from `5V_LOGIC`; wire `DIR` (direction select) and `/OE` per the manufacturer datasheet so **STM32-side ports see 3.3 V CMOS inputs** and **driver-side ports drive 5 V** toward the CL57T/CL42T inputs (often **B→A** when shifting “up” toward the motor driver)

---

## 4. Sensors & Feedback

### 4a. Built-in Encoder Feedback (J1–J4)

The closed-loop kits (CL57T and CL42T) include a **motor-mounted encoder**. The driver reads this internally, closing the current loop without STM32 involvement. The STM32 can still query the driver's actual position register over RS-485 for position telemetry if needed.

### 4b. AS5600 Magnetic Encoders (Optional, J5–J6 only)

> **AS5600 is not part of the J1–J4 wiring.** The closed-loop CL57T/CL42T kits (sec 4a) close the position loop **inside the driver** using their bundled motor encoder. Adding an AS5600 to those joints is redundant and is **not** in the design.

For the open-loop wrist joints, AS5600 is treated as a **Phase 2 / contingency** part:

- **When to add it**: only if measured open-loop drift on J5 or J6 becomes unacceptable in practice. Wrist precision is usually dominated by gear backlash and tool inertia, not stepper resolution, so most builds will skip the AS5600 entirely.
- **Principle**: A small diametrically magnetized magnet glued to the motor shaft rotates above the AS5600 IC. The IC measures field angle and outputs 12-bit position (0–4095 counts per revolution) over I2C.
- **Address conflict**: All AS5600s share the fixed I2C address `0x36`. A **TCA9548A** multiplexer is therefore only needed if **both** wrist encoders are fitted; one AS5600 alone can sit directly on the STM32 I2C bus.
- **Resolution**: 12 bits = 4096 steps/rev → **0.088°/count** raw, well under what the wrist mechanically resolves anyway.

### 4c. A3144 Hall Effect Sensors — Homing

On each joint (J1–J6), an **A3144 Hall effect sensor** and a small neodymium magnet establish the **absolute zero (home) position** at startup:

- The sensor is wired to the **ESP32 joint node** on that link (`HOME` on the local sensor header), not to the base STM32.
- After the base STM32 sends a bus **`HOME`** command, the node sweeps slowly until the Hall output triggers, then stops and zeros its local position reference.
- The base STM32 **orchestrates** homing order (J1 → … → J6); it does not bit-bang STEP/DIR or read Hall pins for remote joints in the distributed harness.

This eliminates reliance on limit microswitches, which have mechanical wear, and keeps homing timing on the same MCU that generates STEP pulses.

---

## 5. Wiring & Signal Integrity

### 5a. Wire Gauge Selection

| Circuit | AWG | Rationale |
|:---|:---|:---|
| Motor phase wires (NEMA 23) | 18 AWG | Up to 4A continuous; silicone jacket for flex and heat |
| Motor phase wires (NEMA 17/14) | 22 AWG | Lower current; smaller and lighter |
| Logic signals (STEP/DIR, I2C) | 22 AWG shielded | Shielding prevents motor PWM noise from corrupting encoder data |
| Power distribution bus | 16 AWG | Main 24V bus from PSU to driver terminal blocks |

### 5b. Connectors

- **GX16 Aviation Connectors**: Locking metal connectors on the control box panel for motor cables. Rated for high vibration.
- **Wire Ferrules (Crimped)**: All wires inserted into screw-terminal blocks (drivers, PSU) are terminated with ferrules. Bare stranded wire under a screw terminal can cold-flow and loosen over time — ferrules prevent this.
- **PET Sleeving & Drag Chain**: Motor cables are bundled in braided PET sleeving and routed through a drag chain at the base rotation joint to protect them from fatigue during continuous J1 sweeps.

### 5c. Harness — Bus vs centralized

**Distributed (target):** Each joint PCB exposes `BUS_IN` / `BUS_OUT` (RS-485 A/B + 24V/GND). Motor phases terminate at the joint. Base board holds STM32 + RS-485 transceiver + Pi UART + 120 Ω termination.

**Centralized (bring-up):** Custom perfboard "hat" on the Nucleo with STEP/DIR/ENABLE to all drivers, 74HC245, Pi UART — see `20_control_signals.yml`.

### 5d. STM32 Breakout / Protoboard (base)

- RS-485 transceiver + DE/RE GPIO
- UART header for Raspberry Pi 4
- 24V distribution to first bus segment
- Optional: legacy STEP/DIR headers during migration

---

## 6. Validation Strategy Without Hardware

If no physical components are on hand, the electrical side can still be validated at the level that matters most right now: power, interfaces, fault handling, and wiring assumptions.

### 6a. What Can Be Checked Now

- **Power budget math**: Recheck PSU headroom, per-rail current, fuse sizing, and startup margin.
- **Interface contracts**: Define exact STEP/DIR/ENABLE polarity, logic levels, fault-pin behavior, and connector pinouts.
- **Signal integrity assumptions**: Confirm that 3.3V to 5V shifting, pullups, and cable lengths are reasonable for the chosen wiring scheme.
- **Safety behavior**: Document what should happen on E-stop, driver alarm, serial timeout, and encoder failure.
- **Harness documentation**: Freeze a wiring table so the physical build later matches the software assumptions.

### 6b. What Is Not Worth Simulating Yet

- Detailed stepper winding physics for every motor.
- Closed-loop behavior of the CL57T/CL42T drivers unless vendor models are available.
- Full EMI/noise behavior of the real harness.

Those are only useful once the actual parts and cable lengths exist. Before that, they add complexity without improving the design much.

### 6c. Recommended No-Hardware Work Products

1. A pin-by-pin electrical map for the STM32, level shifter, drivers, sensors, and power rails.
2. A current budget table that includes peak, average, and fault-state draw.
3. A fault-state matrix showing how the firmware and hardware should respond to each failure.
4. A bench bring-up checklist for when the first PSU, driver, and motor are available.

The corresponding docs are:

- [Electrical interface map](electrical_interface_map.md)
- [Electrical schematic plan](electrical_schematic_plan.md)
- [Electrical bring-up checklist](electrical_bringup_checklist.md)

For this project, that means the immediate electrical deliverable is a **clean interface specification**, not a full circuit simulator.

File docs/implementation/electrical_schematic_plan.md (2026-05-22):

# Electrical Schematic Plan

This is the KiCad-ready block plan for the robot arm electrical system. It describes how the schematic should be split into sheets and what each sheet should contain.

**KiCad project (draft):** [hardware/kicad/robot_arm/robot_arm.kicad_pro](../../hardware/kicad/robot_arm/robot_arm.kicad_pro)

## 1. Top-Level Power Flow

```text
AC mains
  -> IEC C14 inlet + fuse
  -> latching E-stop
  -> Mean Well LRS-350-24
  -> 24V motor bus
  -> motor drivers
  -> logic buck converters
  -> STM32 / sensors / Raspberry Pi 4
```

## 2. Recommended Schematic Sheets

### 2a. Power Entry Sheet

Include:
- IEC C14 inlet
- Fuse holder
- E-stop switch in series with the mains feed
- PSU output terminals
- Main 24V distribution node
- Ground / chassis bonding points

### 2b. Logic Power Sheet

Include:
- 24V to 5V buck converter for logic
- Separate 24V to 5V buck converter for Raspberry Pi 4 (`5V_PI`, ≥3A capable)
- Bulk capacitance on the 5V rail
- Test points for 24V, 5V, and 3.3V

### 2c. STM32 Control Sheet

Include:
- STM32 header / breakout
- 74HC245 level shifter
- UART to Raspberry Pi 4
- RS-485 transceiver to daisy-chained ESP32 joint nodes (see [`distributed_bus_architecture.md`](distributed_bus_architecture.md))
- I2C bus to TCA9548A (optional wrist AS5600 only)
- RS-485 to joint-node daisy chain (no per-joint STEP/DIR at base in distributed mode)
- Pi UART; optional legacy STEP/DIR only for bench bring-up

### 2d. Motor Driver Sheet

Include one repeated channel block per joint:
- Driver power input from 24V rail
- STEP / DIR / ENABLE input signals
- ALARM output
- Motor connector
- Optional encoder connector for closed-loop channels

### 2e. Joint Node Sheet (per link)

Repeat one hierarchical sheet per joint node PCB (ESP32 + local buck + MAX3485 + driver):

- A3144 Hall home sensor header → **ESP32 `HOME` GPIO** (boot homing on the node)
- STEP / DIR / ENABLE / ALARM to the local driver
- RS-485 and 24V daisy in/out
- Optional AS5600 header on **J5/J6 nodes only** (Phase 2)

### 2f. Base Sensor Sheet (optional wrist path)

On the **base** control board only when needed:

- I2C pullups (4.7k to `5V_LOGIC`) for optional wrist AS5600 path (legacy centralized wiring)
- AS5600 + TCA9548A **depopulated by default**

> Production homing does **not** route `HOME_J1`…`HOME_J6` to the Nucleo. Hall sensors live on joint-node boards. Default build: no AS5600s, no mux at the wrist unless drift forces it.

## 3. Net Naming Convention

Use a consistent naming scheme so the schematic remains readable:

- `24V_MOTOR`
- `5V_LOGIC`
- `5V_PI`
- `STM32_STEP_J1` ... `STM32_STEP_J6`
- `STM32_DIR_J1` ... `STM32_DIR_J6`
- `STM32_EN_J1` ... `STM32_EN_J6`
- `DRV_ALARM_J1` ... `DRV_ALARM_J6`
- `NODE_HOME` (per joint-node sheet; not `HOME_Jx` at base in distributed mode)
- `I2C_SCL`, `I2C_SDA`
- `UART_TX`, `UART_RX`

## 4. Design Rules for the Schematic

- Keep motor power separate from logic power until the connector boundary.
- Put all decoupling capacitors near the load they serve.
- Draw the fault path so it is obvious that a driver alarm can disable motion.
- Label every net that crosses a sheet boundary.
- Use repeated hierarchical sheets for the six joints instead of duplicating one-off wiring.
- Keep the schematic human-readable first; PCB optimization comes later.

## 5. KiCad Implementation Order

1. Draw the power-entry and buck-converter sheets.
2. Add the STM32 control sheet and confirm all logic nets.
3. Build one reusable motor-driver sheet for a single joint.
4. Replicate that sheet for all six joints.
5. Add the sensor sheet and verify the I2C and home inputs.
6. Assign footprints only after the schematic netlist is stable.

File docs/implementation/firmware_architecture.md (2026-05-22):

# Firmware Architecture (STM32)

<!--
This document details the low-level firmware running on the STM32 microcontroller:
its responsibilities, control loop design, communication protocol, and safety logic.
-->

## 1. Overview & Role

The STM32 at the base is the **bus master** and **Pi gateway**. Joint-level real-time work (STEP/DIR, homing, driver ENABLE, local watchdog) runs on **ESP32 modules** co-located with each driver — see [`distributed_bus_architecture.md`](distributed_bus_architecture.md). Optional **Wi-Fi** on each ESP32 is for config/logs/OTA only and is **off during motion** — see [`joint_node_connectivity.md`](joint_node_connectivity.md).

The STM32 does not perform trajectory planning or inverse kinematics — those remain on the Raspberry Pi. It receives target joint states over UART, issues RS-485 commands to nodes `1..7`, aggregates telemetry, and enforces system-wide safety (serial timeout, e-stop policy).

**Why a dedicated microcontroller instead of doing everything on the Pi?**
A Linux-based system (including the Raspberry Pi running ROS 2) is not a real-time OS. The scheduler can preempt any process for milliseconds at a time. A stepper motor requires pulse trains generated with microsecond-level precision — a 1ms jitter in pulse timing produces audible stuttering, vibration, and degraded position accuracy. The STM32 solves this with hardware timers that generate STEP pulses entirely in hardware, irrespective of software load.

---

## 2. Responsibilities

### 2a. Step Pulse Generation (STEP/DIR)

The STM32 uses **hardware timer peripherals** (TIM1, TIM2, etc.) in output-compare mode to generate STEP pulses. The pulse frequency directly maps to motor speed:

```
steps_per_second = (target_velocity_deg_per_sec / 1.8) * microstep_divisor
pulse_period_us  = 1,000,000 / steps_per_second
```

*Example*: At 1/16 microstepping, moving at 90°/s = 800 steps/rev × (90/360) × 16 = **3200 pulses/sec** → 312.5 µs per pulse.

The timer auto-reloads at this period. No `delay()` calls, no busy-waiting. The CPU is free to run the PID loop and handle UART simultaneously.

### 2b. Closed-Loop PID Control

Although the CL57T and CL42T drivers handle their own internal closed-loop correction at the driver level, the STM32 can still run a **supervisory position control loop** at the system level when the firmware needs behavior above the driver's built-in correction:

1. **Setpoint**: Target joint angle received from the Raspberry Pi (degrees).
2. **Process Variable**: Current actual joint angle. For J1–J4 this comes from the closed-loop driver itself (over RS-485 or the driver's internal step register). For J5–J6 it comes from the homed step counter, or from an AS5600 if one has been fitted as an optional add-on.
3. **Error**: `e(t) = setpoint - actual`
4. **PID Output**: Adjusts the step pulse frequency (velocity) fed to the driver.

```
u(t) = Kp * e(t) + Ki * ∫e(t)dt + Kd * de(t)/dt
```

The control loop runs at **≥ 1 kHz** (every 1ms) using a SysTick or dedicated timer interrupt. The PID gains (Kp, Ki, Kd) are **stored in flash** for each joint independently and can be tuned over the serial command interface without reflashing.

This makes the PID layer useful for:
- smoothing setpoint changes from ROS / MoveIt,
- compensating for load-dependent lag on joints that expose external position feedback,
- tuning homing and slow approach moves,
- and providing a consistent control abstraction if a joint is later converted from closed-loop driver feedback to external encoder feedback.

It is not meant to replace the driver's own internal correction loop on J1-J4.

> **For the open-loop TMC2209 wrist joints (J5/J6)**: The PID loop is effectively open-loop (encoder feedback not available by default). The STM32 simply commands position by counting pulses from the homed reference. If drift becomes a problem, AS5600 encoders can be added at the wrist.

> **Planned — not yet in repository:** Simulink Embedded Coder output and `joint_controller_generated.cpp` are **not checked in**. Firmware **today** uses only the hand-coded path below.

**Two implementations of this PID layer are planned**, switchable per joint at compile time once codegen exists:

| Path | Source | Status |
|:--|:--|:--|
| **Hand-coded** | `firmware/stm32_core/lib/control/src/pid_controller.cpp`, `joint_controller.cpp` | **In tree** — baseline; Checkpoint A |
| **Generated** | `firmware/stm32_core/lib/control/generated/` + adapter `joint_controller_generated.cpp` | **Planned** — Checkpoint C target; see [`simulink_workflow.md`](simulink_workflow.md) |

The generated path will satisfy the Simulink → firmware contract in [`../Constraints.md §3c`](../Constraints.md): fixed-step discrete at 1 ms, `float32` numerics, velocity-command output, no dynamic allocation. The hand-coded path uses the same interface so swapping is intended to be a single header `#define` when codegen lands.

### 2c. Encoder Reading (I2C — optional path, J5/J6 only)

> The CL57T / CL42T closed-loop kits on **J1–J4** report their position via the driver itself; the STM32 does not poll an external AS5600 for those joints. The I2C / mux code path only exists for **optional** wrist feedback on J5 / J6.

When an AS5600 encoder is connected to a wrist joint:

1. If both J5 and J6 are fitted with AS5600 boards, the STM32 first writes the target channel to the **TCA9548A** I2C multiplexer (address `0x70`). With only one wrist AS5600, the mux is omitted and the AS5600 is addressed directly.
2. STM32 reads the 12-bit angle register from the **AS5600** (address `0x36`).
3. Converts raw count (0–4095) to degrees: `angle_deg = (raw / 4096.0) * 360.0`
4. Feeds the result into the wrist joint's PID loop as the process variable.

When no AS5600 is fitted, the wrist joints run pure open-loop from the homed step counter and skip this code path entirely.

### 2d. Homing Sequence

Homing uses **A3144 Hall effect sensors** — one per joint (J1–J6), mounted on the link with a fixed magnet at mechanical zero. In the **distributed** architecture the Hall line is wired to the **ESP32 joint node** next to that joint's driver, not to the base STM32. See [`distributed_bus_architecture.md`](distributed_bus_architecture.md) § Homing.

**Division of labor**

| MCU | Homing responsibility |
|:---|:---|
| **ESP32 (joint node)** | Autonomous execution: ENABLE, slow STEP/DIR sweep, poll local `HOME` GPIO, stop on Hall trigger, zero local position / step counter |
| **STM32 (base)** | Orchestration only: on Pi `HOME` (`0x04`), send bus `HOME` (`0x23`) to nodes **J1 → J6** in order, wait for each node to report homed via `JOINT_STATE`, then send `HOMED_OK` to the Pi |

On power-up or when the Pi issues `HOME`:

1. STM32 enters a **HOMING** system state and stops forwarding motion setpoints.
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

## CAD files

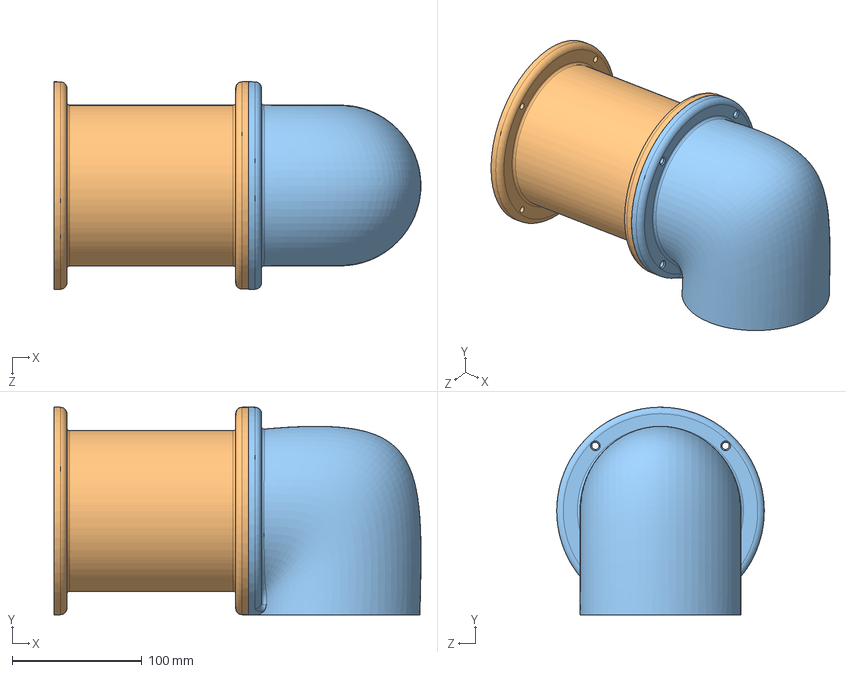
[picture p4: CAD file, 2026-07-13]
mechanical/sw-models/joint3.SLDASM
282.9 x 160.0 x 160.0 mm
link3-part1
link3-part2
perfboard

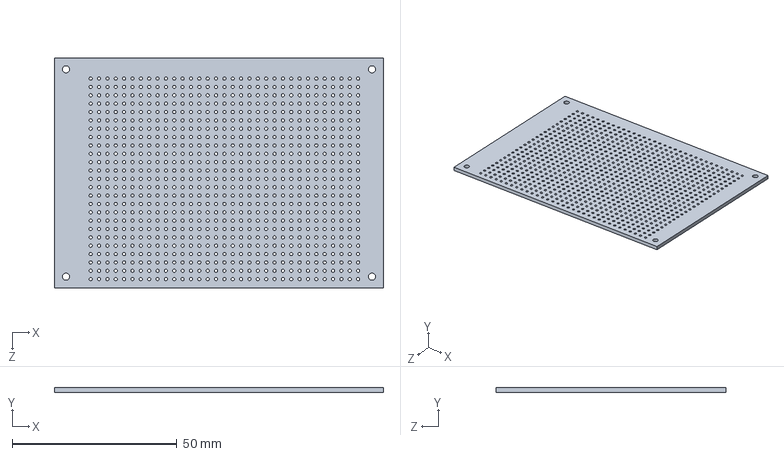
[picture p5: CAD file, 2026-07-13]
mechanical/sw-models/perfboard.SLDPRT
100.0 x 1.45 x 70.0 mm

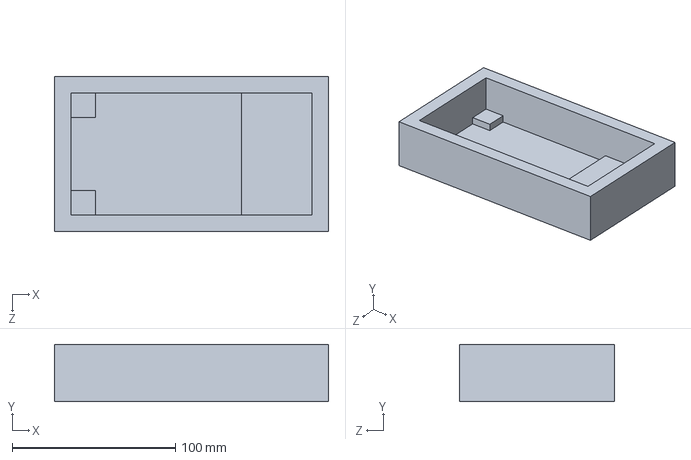
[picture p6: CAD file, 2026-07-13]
mechanical/sw-models/base.SLDPRT
168.0 x 35.0 x 95.0 mm

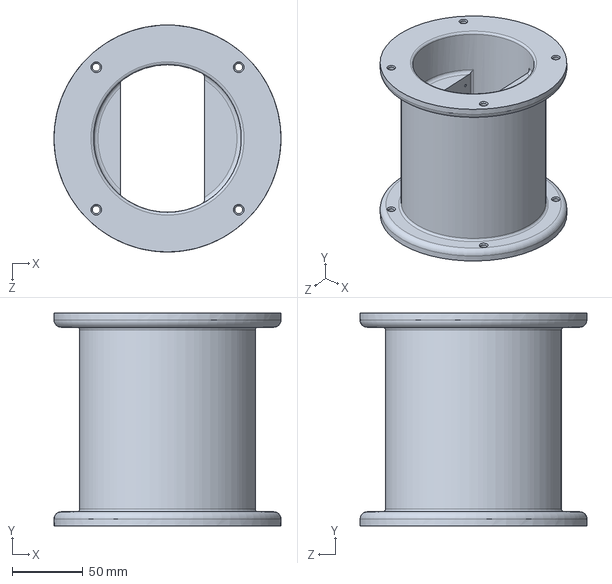
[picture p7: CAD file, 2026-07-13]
mechanical/sw-models/link3-part2.SLDPRT
160.0 x 150.0 x 160.0 mm

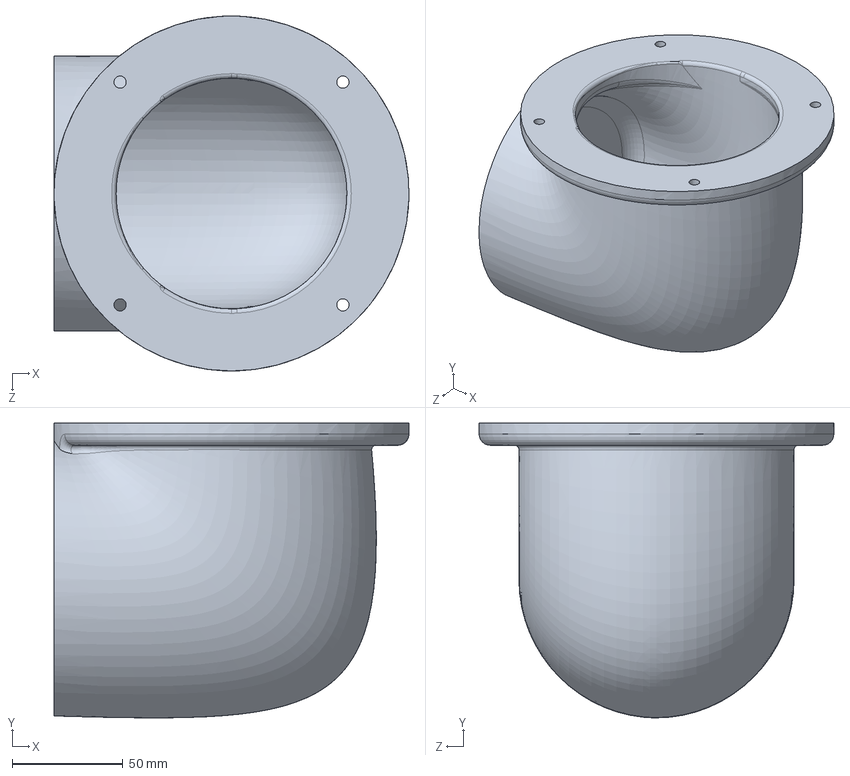
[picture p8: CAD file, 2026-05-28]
mechanical/sw-models/link3-part1.SLDPRT
160.0 x 132.9 x 160.0 mm

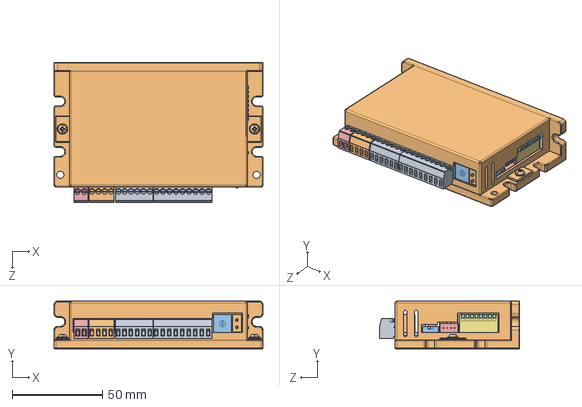
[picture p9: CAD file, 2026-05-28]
mechanical/sw-models/CL42T-V41.STEP
116.0 x 26.5 x 78.0 mm

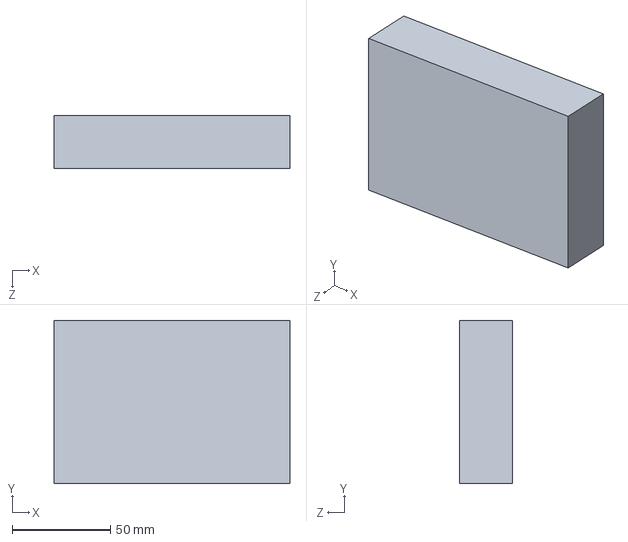
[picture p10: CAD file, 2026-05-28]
mechanical/sw-models/motor-driver-clearance.SLDPRT
120.0 x 83.0 x 27.0 mm

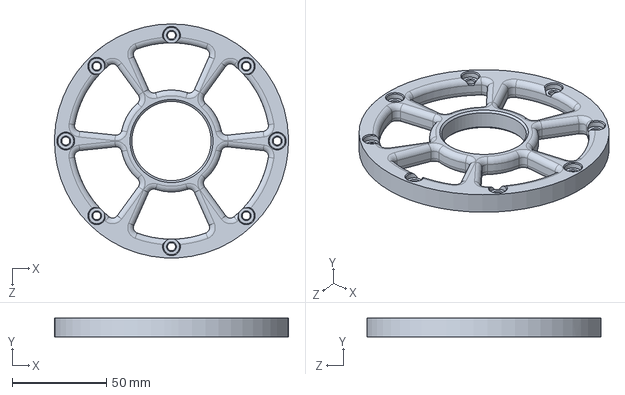
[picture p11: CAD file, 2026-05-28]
mechanical/sw-models/joint1-testing-cycloidal-lid.SLDPRT
123.9 x 10.0 x 124.0 mm

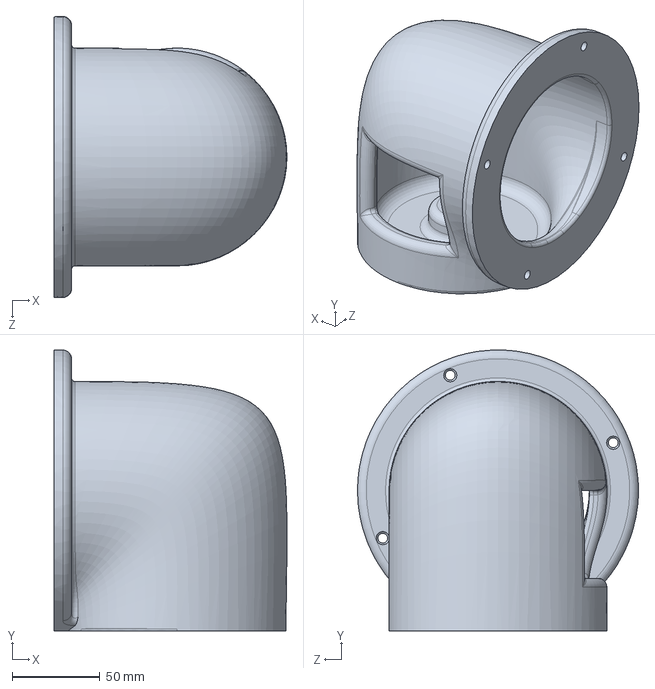
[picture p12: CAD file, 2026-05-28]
mechanical/sw-models/link2.SLDPRT
132.6 x 160.0 x 160.0 mm

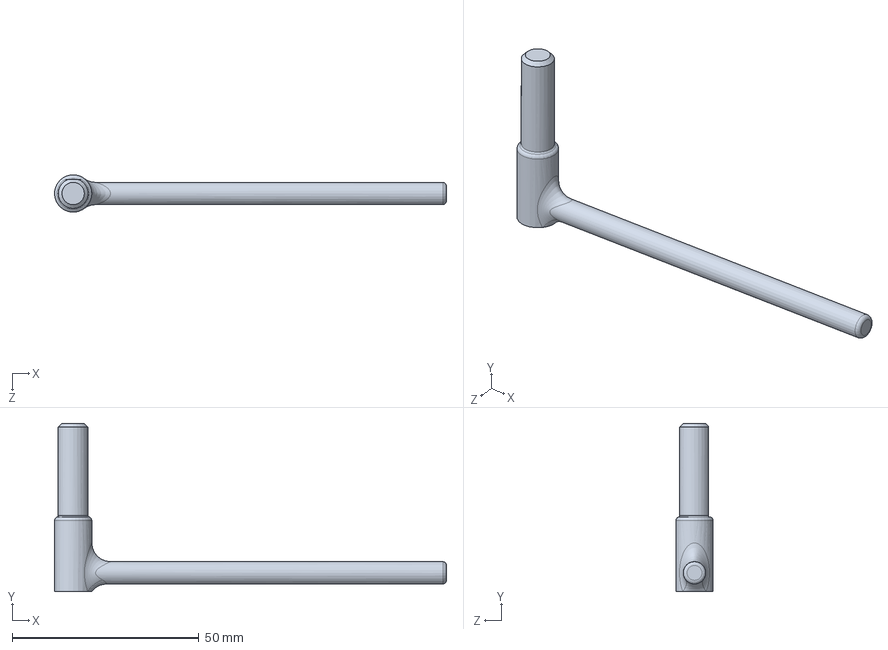
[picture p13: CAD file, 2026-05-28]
mechanical/sw-models/joint1-testing-crank-form-fit.SLDPRT
105.0 x 45.0 x 10.0 mm

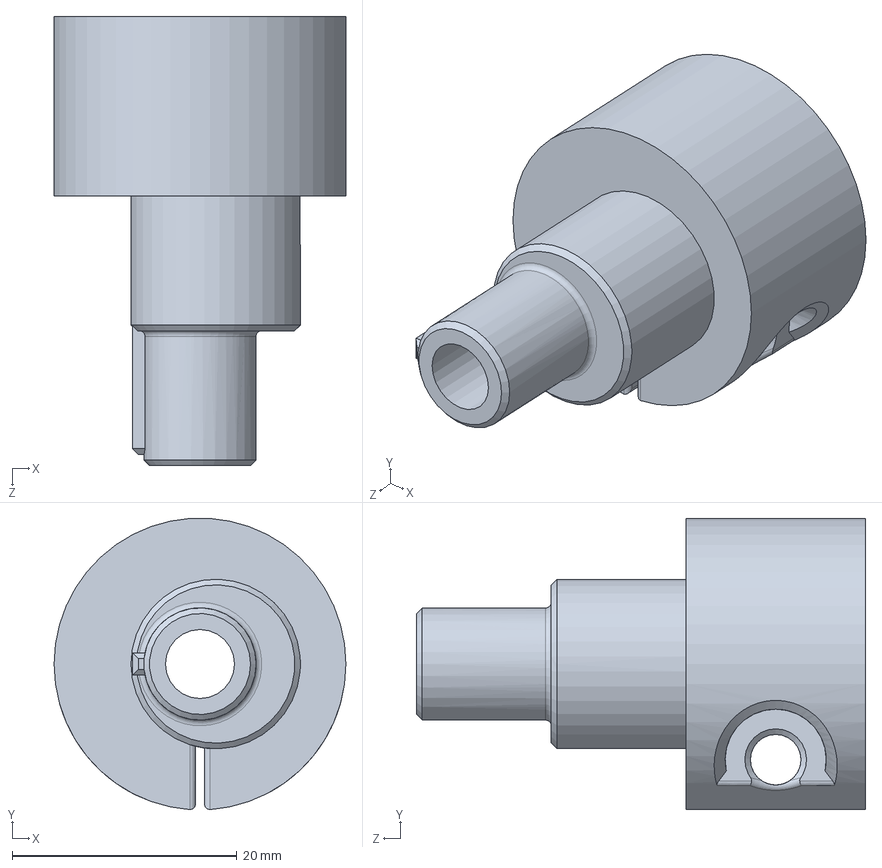
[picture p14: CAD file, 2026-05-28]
mechanical/sw-models/joint2-eccentric-cam1.SLDPRT
26.0 x 25.9 x 40.0 mm

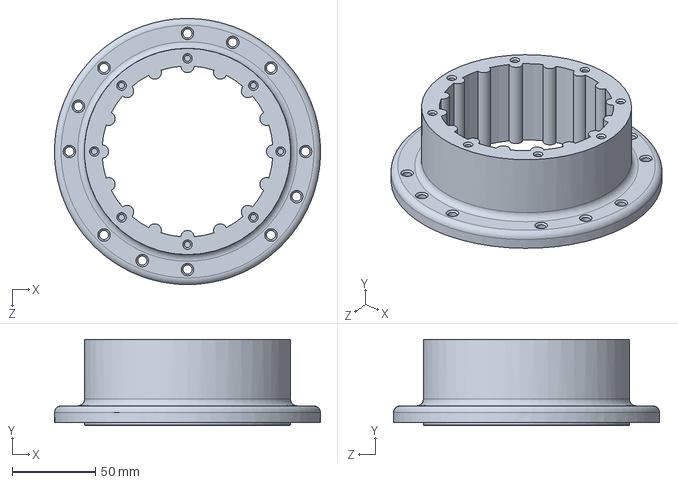
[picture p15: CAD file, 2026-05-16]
mechanical/sw-models/joint2-cycloidal-housing.SLDPRT
159.9 x 52.0 x 160.0 mm

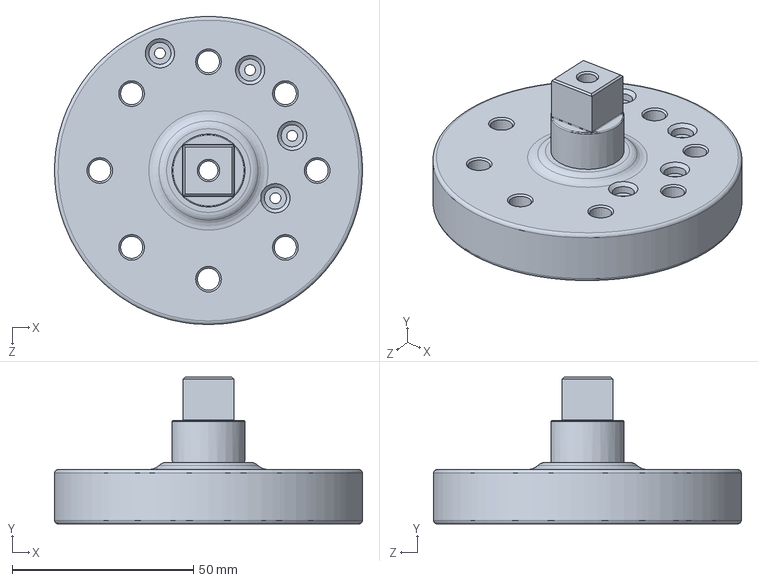
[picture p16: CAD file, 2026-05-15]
mechanical/sw-models/joint2-output-disk.SLDPRT
85.0 x 40.5 x 85.0 mm

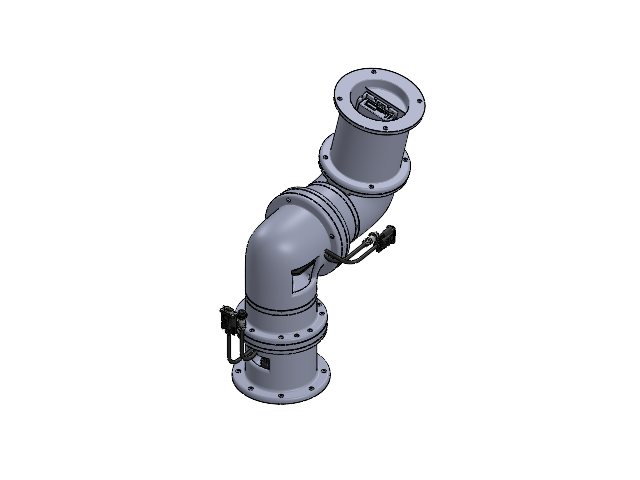
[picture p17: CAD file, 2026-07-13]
mechanical/sw-models/robot-arm.SLDASM
joint1-nema23.step
joint1-cycloidal-housing
joint1-eccentric-cam1
6002-bearing x 4
joint1-cycloidal-disk2
joint1-cycloidal-disk1
joint1-eccentric-cam2
joint1-output-disk
output-pin-6x30 x 8
joint1-cycloidal-lid x 2
6004-bearing x 2
joint1-motor-mounting-plate
link1
joint2-eccentric-cam1
joint2-eccentric-cam2
nema23.step
joint2-motor-mounting-plate
nema23-mounting-bracket.step
link2
joint2-cycloidal-housing
joint2-cycloidal-disk x 2
joint2-output-disk
link3-part1
link3-part2
CL42T-V41.step
perfboard

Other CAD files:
mechanical/sw-models/joint1.SLDASM
mechanical/sw-models/joint2.SLDASM
mechanical/sw-models/joint1-cycloidal-disks.SLDASM
mechanical/sw-models/link3.SLDPRT
mechanical/sw-drawings/joint1-cycloidal-disk1.SLDDRW
mechanical/sw-drawings/joint1-cycloidal-housing.SLDDRW
mechanical/sw-drawings/joint1-cycloidal-lid.SLDDRW
mechanical/sw-drawings/joint1-eccentric-cam1.SLDDRW
mechanical/sw-drawings/joint1-eccentric-cam2.SLDDRW
mechanical/sw-drawings/joint1-output-disk.SLDDRW
mechanical/sw-models/6002-bearing.SLDPRT
mechanical/sw-models/6004-bearing.SLDPRT
mechanical/sw-models/CL42T-V41.SLDPRT
mechanical/sw-models/disk-connector-pin-3x25.SLDPRT
mechanical/sw-models/joint1-cycloidal-disk.SLDPRT
mechanical/sw-models/joint1-cycloidal-disk1.SLDPRT
mechanical/sw-models/joint1-cycloidal-disk2.SLDPRT
mechanical/sw-models/joint1-cycloidal-housing.SLDPRT
mechanical/sw-models/joint1-cycloidal-lid.SLDPRT
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

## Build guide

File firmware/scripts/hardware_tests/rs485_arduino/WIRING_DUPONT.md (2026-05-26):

# RS-485 wiring with few dupont cables

Dupont names describe the **end that plugs onto a pin**:

| Cable | Ends | Use when |
|:---|:---|:---|
| **M–F** | pin + socket | Board has **male** pins (Uno, Nucleo Arduino header) |
| **F–F** | socket + socket | Both sides are **male** pins (two modules with pins up) |
| **M–M** | pin + pin | Breadboard holes, or two female headers |

**Male board pin** → use the **female (socket)** end of an M–F or F–F wire.

You only have **one F–F**? Use it for the **long** hop (see below). Everything else should be **M–F** onto the Arduino/Nucleo headers, or **breadboard jumpers** (no dupont).

---

## Best approach: breadboard (fewest dupont wires)

1. Plug each **MAX485** module into a **breadboard** (pins straddle the center gap).
2. Link **5V / GND / DI / RO / DE** with **short solid jumper wires** on the breadboard (the U-shaped wires that often come with the breadboard — not dupont).
3. Use **only 3 dupont wires** between the two breadboards (bus):
   - **A** (M–F or cut solid wire)
   - **B** (M–F or cut solid wire)
   - **GND** ← good use for your **one F–F** if both ends are male **GND** pins on Nucleo/Uno

4. From **Arduino** to its breadboard: **5× M–F** (or 2 power wires + 3 signal if power is on breadboard from Arduino 5V/GND with M–F).

5. From **Nucleo** to its breadboard: **5× M–F** to the Arduino header row (all **male** pins).

---

## Pin map (all on male headers — M–F friendly)

### Arduino Uno / Nano → MAX485

| MAX485 | Arduino | Wire type |
|:---|:---|:---|
| VCC | **5V** | M–F |
| GND | **GND** | M–F |
| DI | **D9** | M–F |
| RO | **D8** | M–F |
| DE (+ RE) | **D7** | M–F |
| A, B | To other module (see bus) | 2 wires |

**D7, D8, D9** are beside each other on the Uno — run the three signal wires as a tight group.

### Nucleo-F401RE → MAX485 (firmware uses these pins)

| MAX485 | Nucleo (Arduino header) | STM32 pin |
|:---|:---|:---|
| VCC | **3.3V** | — |
| GND | **GND** | — |
| DI | **D8** | PA9 |
| RO | **D2** | PA10 |
| DE (+ RE) | **A2** | PA4 |
| A, B | To other module | — |

**Do not use morpho (CN10/CN12) pins** unless you have morpho dupont — use **D8, D2, A2, 3.3V, GND** on the side Arduino connector only.

**Do not remove the CN2 jumpers** on the Nucleo (middle of the board). They connect ST-Link to the STM32 for flash/debug. If CN2 is off, `pio upload` fails with `unable to connect to the target` even though USB and serial still work.

`D2` is digital pin 2 on the silkscreen (not “D02”). `A2` is analog pin 2.

### Bus between the two MAX485 boards (minimum 3 connections)

| Signal | Connect |
|:---|:---|
| **A** ↔ **A** | 1 wire |
| **B** ↔ **B** | 1 wire |
| **GND** ↔ **GND** | 1 wire (**use your F–F here** if both GND points are male pins) |

**Minimum to test:** 3 bus wires + 5 wires per board to its MCU = **13** connections total. A breadboard cuts that to **3 bus duponts + a few M–F to each board**.

---

## If you truly only have one jumper wire right now

You **cannot** run the full test with one wire. Minimum for *any* bus activity:

1. **Common GND** between Nucleo, Arduino, and both modules (your **one F–F** can do Nucleo GND ↔ Arduino GND).
2. Still need **A**, **B**, and **five wires per MCU↔module** — borrow M–M breadboard jumpers, solid core wire, or a cheap **M–F 40-pin dupont set** (~$2).

**Priority order** if you can only add wires one at a time:

1. **GND** (common reference) — use the F–F between Nucleo and Arduino **GND**
2. **A** and **B** between modules
3. Power + UART on each side (VCC, DI, RO, DE)

---

## Wire gender cheat sheet (this bench)

```text
[Nucleo male pin D8] ←── socket end of M–F ──→ [MAX485 male pin DI]
```

Wrong: **pin end of M–M** onto Nucleo male pin (won’t stay on).

Wrong: **F–F** onto a **female** screw-terminal only module (use bare wire in the screw terminal).

---

## No breadboard?

- Solder **solid core wire** (22–26 AWG) to the MAX485 module pads, or
- Hold **M–F** wires by pressing the socket onto the pin with a small dab of tape (bench only).

---

## After rewiring

Re-flash both boards (pins changed on Nucleo):

```sh
cd firmware/scripts/hardware_tests
./run_rs485.sh
```

Arduino sketch unchanged (still D7/D8/D9).

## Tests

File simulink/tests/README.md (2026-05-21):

# Simulink Tests

> **Planned — not yet in repository** — no test harness models are checked in. See [`../../docs/implementation/simulink_workflow.md`](../../docs/implementation/simulink_workflow.md).

Simulink Test harnesses for the plant models and controllers.

## Planned harnesses

| File | Tests |
|:--|:--|
| `plant_step_response.slx` | Apply a known torque step to each plant model and verify the steady-state velocity matches the expected motor torque-speed curve within ±5%. |
| `controller_tracking.slx` | Drive each closed-loop controller with a reference trajectory; assert tracking error stays within the spec in `docs/Constraints.md §3a`. |
| `codegen_equivalence.slx` | Run the original Simulink controller and the code-generated version against the same input sequence; assert outputs match bit-for-bit (Embedded Coder's standard "SIL" test). |

The `codegen_equivalence` test is the contract that lets us trust the generated C without re-validating it on hardware after every regeneration.

## Running

```matlab
sltest.testmanager.run('plant_step_response.mldatx')
```

Tests are run manually in MATLAB for now. CI integration is deferred — running headless MATLAB in CI requires either a self-hosted runner or MathWorks' GitHub Action (which requires a network license server).

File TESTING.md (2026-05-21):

# Testing

Commands below mirror [`.github/workflows/ci.yml`](.github/workflows/ci.yml).
First-time setup: [`./scripts/setup.sh`](scripts/setup.sh).

## Verification matrix

| Layer | Local command | CI job |
|---|---|---|
| Firmware (host / native) | `./firmware/scripts/test.sh` | `firmware-native-tests` |
| Firmware (Renode smoke) | Build `nucleo_f401re_renode`, run `simulation/renode/tests/firmware_smoke.robot` | `firmware-build-and-renode` |
| ROS / MoveIt behavioral | `./software/scripts/test.sh` (requires Docker) | `software-behavioral-tests` |
| Simulation (Python) | `./simulation/scripts/test.sh` | `simulation-tests` |

**Requirements:** PlatformIO (`pio`), Docker for ROS tests, Python 3.11+ for simulation.

## Firmware native tests

Runs PlatformIO `native` environment and the C++ harness under
`firmware/stm32_core/test/` (packet codec, PID, joint limits, driver scaffolds, etc.).

Some tests document **intentional scaffolds** (`TODO(contributor)`, `PENDING`) — see
[`firmware/CONTRIBUTING.md`](firmware/CONTRIBUTING.md).

## Hardware tests (manual, not in CI)

On-target scripts under `firmware/scripts/hardware_tests/` — run only on the bench
with motors powered and safeguards in place.

## Expected scaffold behavior

- **Simulation FK/IK:** pytest may assert placeholder behavior until the DH chain is complete.
- **JointController::Step:** partial implementation; native tests encode the contract.

These are not CI failures by design until the corresponding tier is implemented.

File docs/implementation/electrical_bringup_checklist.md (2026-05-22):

# Electrical Bring-Up Checklist

This checklist is for the first time hardware is available. It is intentionally conservative so the system can be validated without risking the PSU, drivers, or controller.

## 1. Prerequisites

- One PSU
- One driver channel
- One motor
- One A3144 home sensor (to the **joint-node** ESP32 in distributed builds, or to the bench STM32 in centralized bring-up)
- One logic power supply
- One current-limited bench setup or fused power path
- Multimeter
- If available, an oscilloscope or logic analyzer

## 2. Pre-Power Checks

- Verify the wiring harness against the interface map.
- Confirm connector pin 1 orientation on every harness.
- Check for continuity between intended nets only.
- Check for shorts between 24V, 5V, and ground.
- Confirm the E-stop really removes power from the motor rail.
- Confirm logic ground and motor ground are connected where intended, and only where intended.

## 3. Power-Up Sequence

1. Power the logic rail only.
2. Confirm STM32 boots.
3. Confirm the UART link to the Raspberry Pi is alive.
4. Confirm the I2C bus sees the mux and encoder hardware if fitted.
5. Power the motor rail with the motor disconnected.
6. Confirm driver idle current and fault state.
7. Connect one motor and repeat the idle check.

## 4. Single-Axis Validation

- Command a small STEP/DIR motion at low speed.
- Verify the motor turns in the expected direction.
- Verify ENABLE disables motion cleanly.
- Verify ALARM stops motion and is reported to firmware.
- Verify the Hall home sensor toggles at the expected mechanical position (read on the joint-node ESP32, or STM32 GPIO on centralized bench).
- On a joint node: send bus `HOME` from the STM32 master (or a bus test script) and confirm autonomous sweep + zero latch.
- If using an encoder, verify angle changes match physical rotation.

## 5. Safety Validation

- Press E-stop during idle.
- Press E-stop during motion.
- Unplug the home sensor and verify the system fails safely.
- Force a driver alarm if the driver supports it.
- Disconnect the serial link and confirm the watchdog behavior.
- Restore power and confirm the arm does not move unexpectedly.

## 6. Acceptance Criteria

The first joint is considered healthy when:
- It powers up without fault.
- It homes repeatably.
- It can move a short commanded distance and stop accurately.
- The driver fault line is observed and handled correctly.
- No connector, regulator, or driver runs unreasonably hot during a short test.

## 7. Expansion Rule

Do not bring up the next joint until the current joint passes the checklist above.

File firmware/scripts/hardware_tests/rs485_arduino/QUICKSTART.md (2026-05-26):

# RS-485 bench test — quick start (PlatformIO)

Two boards, two MAX485 modules, **38400 baud** on the RS-485 bus (USB monitors stay 115200). No Arduino IDE required.

## 1. Wire

| | Arduino Uno/Nano | Nucleo-F401RE |
|:---|:---|:---|
| MAX485 VCC | 5V (or 3.3V if 3.3V module) | **3.3V** |
| MAX485 GND | GND | GND |
| DI | **D9** | **D8** |
| RO | **D8** | **D2** |
| DE | **D7** | **A2** |

**Between modules:** A↔A, B↔B, **Arduino GND ↔ Nucleo GND** (required).

## 2. Flash Arduino (PlatformIO)

From the repo:

```sh
cd firmware/scripts/hardware_tests
chmod +x run_rs485_arduino.sh   # once
./run_rs485_arduino.sh uno      # or: nano | mega
```

Or manually:

```sh
cd firmware/scripts/hardware_tests/rs485_arduino
pio run -e uno -t upload
pio device monitor -e uno
```

**VS Code / Cursor:** open folder `firmware/scripts/hardware_tests/rs485_arduino` as the PlatformIO project, pick env `uno` / `nano` / `mega`, Upload + Monitor.

Leave the monitor open (or note the COM port) — you should see the banner and `Ready — waiting for RS485 PING...`.

## 3. Flash STM32 (second USB port / cable)

In another terminal:

```sh
cd firmware/scripts/hardware_tests
./run_rs485.sh
```

## 4. Pass criteria

**STM32 monitor:** every ~1 s, `TX: RS485 PING` and `RX (12 OK)` when echo is clean.

**Arduino monitor:** `RX (12 OK)` and `TX echo` — `bad=` should stay near zero.

For a long harness later: add **120 Ω** between A and B at each bus end; keep **GND** reference.

## 5. Troubleshooting

- Common **GND** Arduino ↔ Nucleo
- Swap **A** and **B** on one module
- Wrong board env: `pio run -e nano` for Arduino Nano, etc.
- List ports: `pio device list`

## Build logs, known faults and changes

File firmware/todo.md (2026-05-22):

# Firmware Roadmap

Low-level control: **STM32 bus master** at the base + **ESP32 joint nodes** on RS-485 ([`docs/implementation/distributed_bus_architecture.md`](../docs/implementation/distributed_bus_architecture.md)).

## Distributed bus (scaffold landed)

- [x] Shared `firmware/lib/bus_protocol/` + native tests
- [x] `firmware/joint_node/` PlatformIO (`node_j1` … `node_gripper`, NVS ID override)
- [x] `firmware/stm32_core/lib/bus/BusMaster` scaffold
- [ ] STM32 RS-485 UART + DE driver
- [ ] ESP32 STEP/DIR + homing FSM + gripper PWM
- [ ] Joint node MOTION/SERVICE modes — Wi-Fi off in MOTION ([`joint_node_connectivity.md`](../docs/implementation/joint_node_connectivity.md))
- [ ] Joint profile table (driver type, limits per node ID)
- [ ] Pi protocol: STM32 aggregates bus telemetry into `JOINT_STATE` packets

---

The backlog is organized around the **staged delivery checkpoints A–F** defined in [`docs/Application.md`](../docs/Application.md#3-staged-delivery-plan). Each checkpoint lists the firmware work required to unlock it. Items marked *Phase 1* are needed before any real-arm demo; *Phase 2* items are unlocked once the full 6-axis hardware is built.

**Learning path**: Tier 1 exercise stubs (`JointController::Step`, `StepperDriver` under `stm32_core/lib/`) and the fuller product backlog described below intentionally overlap — the boxes here are broader themes (architecture, tooling, ROS), while onboarding steps live in **[`firmware/CONTRIBUTING.md`](CONTRIBUTING.md)** with concrete filenames.

---

## Checkpoint A — "It moves" *(Phase 1, J1 + J2 only)*

*Exit criterion: STM32 drives J1 and J2 to commanded positions via simple serial commands; encoder/driver feedback reports back actual angle.*

### A.1 Pre-hardware / analysis
- [ ] **Electrical Interface Map**: Define pinouts, logic levels, connector assignments, and fault-line behavior for J1 + J2.
- [ ] **Current Budget Check**: Verify peak, average, and startup current against the PSU and logic buck converters.
- [ ] **Fault-State Matrix**: Specify firmware responses for E-stop, driver alarm, serial timeout, encoder failure, and I2C bus hang.
- [ ] **Protocol Mocking**: Add host-side tests or stubs that validate packet framing and command parsing without real hardware.

### A.2 Core firmware (J1 + J2)
- [ ] **Serial Protocol**: Define and implement the binary UART/USB command protocol (`[0xAA 0x55][CMD][PAYLOAD][XOR]`) between RPi and STM32.
- [ ] **Stepper Core**: Implement precise timer-based pulse generation for CL57T drivers on J1 and J2.
- [ ] **State Machine**: Implement IDLE / MOVING / HOMING / ERROR states for the 2-DOF subset.
- [ ] **Driver Validation**: Confirm STM32 reliably drives both NEMA 23 (via CL57T) on J1 and J2 at varying speeds, with the 74HC245 level shifter in the loop.
- [ ] **Homing Logic**: ESP32 Hall FSM per joint; STM32 orchestrates J1→J2 on bus `HOME` (see `distributed_bus_architecture.md`).

---

## Checkpoint B — "It moves in sim" *(no firmware-side work)*

This checkpoint is purely software/URDF — firmware remains at Checkpoint A. Listed here only so the cross-reference is explicit.

---

## Checkpoint C — "It plans" *(Phase 1)*

*Exit criterion: MoveIt-planned trajectory streams to the STM32 and executes on J1 + J2 with < 1° per-joint error vs. the Gazebo dry-run; the same trajectory also runs in Simscape against the per-joint Simulink controller with three-way agreement (Gazebo + Simscape + real) within ±5° per joint.*

- [ ] **`FollowJointTrajectory` ingestion**: STM32 accepts and interpolates trajectory waypoints at the 50–100 Hz update rate that MoveIt streams (see `docs/Constraints.md §4b`).
- [ ] **Supervisory PID Position Loop (hand-coded baseline)**: Implement on top of the CL57T's internal closed loop; corrects integrated position error reported back to the Pi. This is the Checkpoint A controller and stays as the fallback path.
- [ ] **Generated-Controller Adapter (`joint_controller_generated.cpp`)**: Wraps the Embedded-Coder-generated joint PID functions (from `simulink/codegen/output/`) into the firmware's `JointController::Step` hook. See [`docs/implementation/simulink_workflow.md §3a`](../docs/implementation/simulink_workflow.md). Must compile cleanly **without** MATLAB on the build host.
- [ ] **Codegen Integration Smoke Test**: Run the generated controller against a unit-test fixture and assert it agrees bit-for-bit with the Simulink reference output (Software-in-the-Loop equivalence, `Application.md §2c M7`).
- [ ] **Per-trajectory Safety Envelope**: Reject incoming setpoints that violate joint angle limits (`docs/Constraints.md §3d`) — must fail safely, not clip silently. Adapter re-applies the clamp on controller output as defense-in-depth (`docs/Constraints.md §3c`).
- [ ] **Telemetry Stream**: Publish per-joint actual angle + driver fault status back to the Pi at ≥ 50 Hz for sim-to-real comparison (`Application.md §2c M4`).

---

## Checkpoint D — "It sees" *(Phase 2; vision is host-side, firmware only needs to be ready)*

*Exit criterion: Firmware reliably executes pick / place trajectories handed down by the vision-driven task node.*

- [ ] **Gripper Channel**: Add a `SET_GRIPPER` command path (servo PWM for MG996R, or solenoid GPIO for the suction variant).
- [ ] **Move-Then-Settle Reporting**: STM32 emits a `MOVE_COMPLETE` packet only when all joints are within tolerance and stationary — required by the pick step to avoid grasping while moving.

---

## Checkpoint E — "It tends" *(Phase 2)*

*Exit criterion: STM32 supports the full print-tending cycle without firmware-side intervention.*

- [ ] **Multi-Axis Sync**: Synchronize movement across all 6 joints for smooth trajectories (Bresenham's or equivalent multi-axis interpolation).
- [ ] **Global Error Handling**: Cross-axis safety — if any joint stalls or faults, halt all joints and emit `FAULT`.
- [ ] **Safety Interlocks**: Hardware E-Stop interrupt handler (must override software state); current sensing on the 24V bus.
- [ ] **EEPROM Storage**: Save calibration offsets, soft limits, and PID tunings to non-volatile memory for all 6 axes.
- [ ] **Tuning & Optimization**: Re-tune PID loops in Simulink against the updated all-joint plant models; regenerate via Embedded Coder; the firmware only consumes the regenerated source (no hand-tuned gain edits in firmware).
- [ ] **Gravity-Compensation Feed-Forward (J2)**: Integrate the Simulink-designed feed-forward path for J2 to handle full-extension payload during the pick step.
- [ ] **Communication Stress Test**: Validate high-speed command streaming during a full tending cycle without dropped packets.

---

## Checkpoint F — "Sim predicted it" *(Phase 2 stretch; firmware support only)*

- [ ] **Timestamped Telemetry**: Pair every reported joint angle with its STM32 timestamp so the sim-vs-real comparison plot has unambiguous time alignment.

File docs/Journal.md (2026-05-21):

<!-- 
Use this file to journal development with wins, problems encountered, and whatever else... 
-->

Mar 26: cycloidal disk

May 17: **Scoping decision — picked the headline application and method.**

Up to this point the project had no concrete end goal beyond "build a 6-DOF arm." This was hurting on two fronts: (1) hard to justify design trade-offs without a workload to reference, and (2) hard to communicate what the project actually *does* on a resume.

Picked **autonomous 3D-print bed tending** as the headline application, with **sim-to-real via a Gazebo digital twin** as the method that wraps around it. Rationale captured in [`Application.md`](Application.md); key points:

- Print tending lives comfortably inside the existing mechanical envelope (free-space motion + top-down grasp, ±2 mm placement tolerance) — no redesign required.
- The application emerged naturally from the build itself: the arm tends the printers that produce its own structural parts. Clean narrative.
- Sim-to-real is constrained to **L1 (digital twin) + L2 (planner-in-the-loop)** — explicitly not RL/domain-randomization. The free-space pick task doesn't justify a learned policy, and the scope discipline keeps the project shippable.
- Delivery is sequenced into **independently demo-able checkpoints A→F** so that if any milestone slips, the previous one is still a complete artifact (video / GIF / write-up).

Updated `README.md`, `Scope.md`, and `Constraints.md` to reference `Application.md` rather than restating the goal. Reorganized the three subsystem `todo.md` files around checkpoints A–F.

Next concrete step: Checkpoint B — load preliminary J1+J2 URDF into RViz and confirm joint sliders drive both the sim and the real arm.

May 17 (later): **Added Simulink / Simscape / Embedded Coder to the toolchain.**

Rationale: hand-tuning the joint PID on the real arm is slow, risky, and unrepeatable (gear backlash and friction drift). Designing against a Simscape Multibody plant model lets the controller converge offline; Embedded Coder then carries the *exact* tuned controller bit-for-bit to the STM32. This is also the standard workflow at automotive / aerospace OEMs and is a strong resume signal for those teams.

Scope decisions:

- Simulink work lives in a new top-level `simulink/` directory, parallel to `simulation/`. Three simulators total — Python FK/IK, Simscape (Simulink), and Gazebo — each catching a different class of bug. See [`Scope.md §2e`](Scope.md#2e-model-based-design--codegen-simulink) for the layering rationale.
- **Planned (not in repo yet):** Generated C from Embedded Coder would live under `simulink/codegen/output/` so the firmware build does not require a MATLAB license.
- **Planned:** The codegen → firmware boundary is a single hand-written adapter (`joint_controller_generated.cpp`); see [`Constraints.md §3c`](Constraints.md) for the contract. Firmware today uses hand-coded control only.
- Scope-disciplined: Simulink is for **joint-level control design + codegen**, not for replacing MoveIt or the system-level Python tooling. Anti-patterns documented in [`implementation/simulink_workflow.md §6`](implementation/simulink_workflow.md).
- The Simulink milestone slots into Checkpoint C (`Application.md §3`): same trajectory in Gazebo, Simscape, and on the real arm — three-way agreement within ±5° per joint is the exit criterion.

Updated `Scope.md`, `Constraints.md` (new §3c), `Application.md` (new M6–M8 + revised Checkpoint table), `firmware/todo.md`, `simulation/todo.md`, root `README.md`, and `docs/implementation/firmware_architecture.md`. Created `docs/implementation/simulink_workflow.md` as the central reference.

Next concrete step on the Simulink side: write `simulink/scripts/setup_workspace.m` and `joint_params.mat` from the existing constants in `Constraints.md` / `Calculations.md` so any future model has a single source of parameter truth.

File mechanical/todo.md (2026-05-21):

# Mechanical Roadmap

> **Drive design:** J3–J4 use **cycloidal reducers** on driven joints (see [`docs/Design_Choices.md`](../docs/Design_Choices.md)). The belt-drive item in INTEGRATION below is legacy brainstorming unless you explicitly choose belts for the wrist.

This document outlines the mechanical design, CAD, 3D printing configurations, and assembly instructions.

## DEVELOPMENT
*Prototyping, dimension verification, and testing print tolerances - before full BOM procurement.*

- [ ] **Gearbox Prototyping**: Test print and validate gear reduction designs (e.g., Cycloidal, Planetary, or Harmonic) for backlash, tolerances, and friction.
- [ ] **Material Testing**: Calibrate PETG/ABS print settings for strength, layer adhesion, and dimensional accuracy for heat-set inserts.
- [ ] **Motor Fitment Tests**: Print isolated mounts for NEMA 23, NEMA 17, and Servos to physically verify bolt holes, shaft lengths, and alignments using prototype motors.
- [ ] **Bearing Tolerances**: Print test gauges to verify press-fit tolerances for 608ZZ bearings and thrust bearings.
- [ ] **Base & Joint 1 CAD**: Design the high-torque base housing and thrust bearing integration.
- [ ] **Shoulder (Joint 2) CAD**: Design shoulder linkage and structural reinforcement for vertical lift.

## INTEGRATION
*Final prints, sourcing, and assembly - after purchasing all hardware.*

- [ ] **Mass Printing**: Print all structural arm sections, linkages, and housings with high infill/wall count.
- [ ] **Hardware Sourcing**: Procurement of all M3/M4 bolts, nuts, bearings, belts, and brass inserts.
- [ ] **Sub-assembly - Base & Shoulder**: Install bearings, press-fit motors, and assemble the primary lifting joints.
- [ ] **Wrist / upper-arm drives**: Install cycloidal stages per current CAD (legacy note: GT2 belts were an earlier concept — use cycloidal design unless intentionally changed).
- [ ] **Cable Management**: Route power, encoder, and motor cables through the internal pathways of the linkages.
- [ ] **End-Effector Integration**: Attach the 2-DOF wrist and modular gripper.
- [ ] **Static Stress Test**: Verify the fully assembled arm doesn't deflect significantly or back-drive under its own weight when powered off.

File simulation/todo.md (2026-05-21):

# Simulation Roadmap

This document outlines the **system-level** kinematic models and physics simulation environments (Python FK/IK + Gazebo) — the **sim** half of the sim-to-real pipeline defined in [`docs/Application.md §2`](../docs/Application.md#2-method--sim-to-real-via-digital-twin).

> **Joint-level dynamics (motor + cycloidal + link) and per-joint controller design live in [`/simulink/`](../simulink/README.md)** — see [`docs/implementation/simulink_workflow.md`](../docs/implementation/simulink_workflow.md) for that split.

The backlog is organized around the **staged delivery checkpoints A–F**. Simulation work is front-loaded toward Checkpoints B–C (digital twin + planner-in-the-loop) since those define the entire method.

---

## Checkpoint A — "It moves" *(no simulation work)*

---

## Checkpoint B — "It moves in sim"

*Exit criterion: A URDF of J1 + J2 loads in RViz and matches the physical arm pose when driven by the same joint commands.*

- [ ] **DH Parameter Estimation**: Draft Denavit-Hartenberg parameters for J1 + J2 from preliminary CAD dimensions (`dh_solver.py`).
- [ ] **Forward Kinematics (FK)**: Pure Python FK solver to validate coordinate transforms (numpy only — no ROS dependency, fast to iterate).
- [ ] **URDF — Primitive Geometry**: Build the J1 + J2 URDF using cylinders/boxes to model the joint hierarchy. Real meshes come later.
- [ ] **RViz2 Visualization**: ROS 2 launch file that loads the primitive URDF, publishes `/tf`, and accepts `/joint_states` from either the GUI slider node or the real hardware bridge.
- [ ] **Dimensional Validation**: Measure the real assembled arm vs. the URDF; iterate until link lengths agree within ±2 mm (`docs/Application.md §2c M1`).

---

## Checkpoint C — "It plans"

*Exit criterion: MoveIt produces a trajectory in sim; the same trajectory executes on real hardware with per-joint error matching the dry-run within ±5°.*

- [ ] **Inverse Kinematics (IK) Prototyping**: Implement and test analytical IK on the 2-DOF subset to sanity-check MoveIt's TRAC-IK output.
- [ ] **Visual Assets**: Export J1 + J2 CAD parts to STL, decimate, link as visual meshes in the URDF (collision meshes remain primitive for speed).
- [ ] **Inertia Tensors**: Extract mass + COM + inertia from CAD for J1 + J2 links. Required for any future Gazebo physics — Gazebo will silently accept zero-inertia URDFs and produce nonsense (`docs/Constraints.md §4d`).
- [ ] **Sim vs. Real Telemetry Logger**: A Python script that records the planned trajectory, the actual STM32-reported angles, **and the Simscape-predicted angles** (exported from Simulink as CSV), computes per-joint error across all three, and renders a plot. This is the artifact that proves Checkpoint C (`Application.md §2c M8`).

---

## Checkpoint D — "It sees" *(camera-side sim is optional)*

- [ ] **Camera Frame in URDF**: Add the overhead camera as a fixed link with a known transform to the print bed frame, so MoveIt understands where vision data is anchored.
- [ ] *(Optional)* **Simulated Camera in Gazebo**: Use Gazebo's camera plugin to render a synthetic bed view — enables dry-running the part-localization pipeline before the real camera is mounted.

---

## Checkpoint E — "It tends" *(physics fidelity matters now)*

*Exit criterion: A Gazebo simulation runs the full tending state machine and behaves qualitatively like the real arm.*

- [ ] **URDF Refinement (all 6 joints)**: Extract actual physical properties (mass, COM, inertia tensors) from final CAD for J3–J6 and update the URDF.
- [ ] **All-Link Visual Assets**: Export, decimate, and link STLs for all six links.
- [ ] **Gazebo / Ignition Setup**: Configure a physics world with joint friction, gravity, and collision models. Include a static printer + bed + bin in the scene.
- [ ] **ros2_control Gazebo Plugin**: Implement `ros2_control` hardware interfaces in Gazebo so the same control stack runs in sim and on hardware unchanged.
- [ ] **Stepper Dynamics Approximation**: Model torque rolloff vs. speed and microstepping behavior at least crudely — pure-velocity joints will not predict cycloidal compliance failures.

---

## Checkpoint F — "Sim predicted it" *(stretch)*

*Exit criterion: One command runs the tending sequence in Gazebo, then on the real arm, and produces a side-by-side video + a per-joint error report.*

- [ ] **Digital Twin Validation Suite**: Standard battery of trajectories run in both sim and real, with auto-generated comparison plots. Becomes the regression test for any URDF or controller change.
- [ ] **URDF Tuning Loop**: When sim and real disagree by > 5° on any joint, automatically flag which URDF parameter (link length, inertia, joint damping) is the most likely culprit. This operationalizes the "simulation is the specification" philosophy from `docs/Scope.md §1`.

---

## Out-of-scope

- Domain-randomized RL training pipelines (`Application.md §2b` — L4 is explicitly out of scope for v1).
- Photorealistic rendering or Isaac Sim integration (Gazebo is sufficient for L1 + L2 transfer).

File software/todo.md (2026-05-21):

# Software Roadmap

This document outlines the high-level control logic and ROS 2 workspace running on the Raspberry Pi.

The backlog is organized around the **staged delivery checkpoints A–F** defined in [`docs/Application.md`](../docs/Application.md#3-staged-delivery-plan). Each checkpoint lists the software work required to unlock it.

---

## Checkpoint A — "It moves" *(minimal Pi involvement)*

*Exit criterion: A simple host-side Python script can issue `SET_JOINTS` packets and watch J1 / J2 move.*

- [ ] **Serial Sender (no ROS yet)**: A small Python utility that opens the STM32 serial port, frames a `SET_JOINTS` packet, and reads back telemetry. Used to validate the firmware before any ROS plumbing.

---

## Checkpoint B — "It moves in sim"

*Exit criterion: URDF loads in RViz; joint sliders drive the real arm in lockstep with the visualized model.*

- [ ] **ROS 2 Workspace Setup**: Package structure for `robot_core` and `robot_description` (skeleton already present).
- [ ] **URDF — J1 + J2 subset**: Pull link lengths from CAD; populate masses + inertia tensors so Gazebo physics is meaningful later (`docs/Constraints.md §4d`).
- [ ] **Hardware Bridge Node**: ROS 2 node that bridges `/joint_commands` → STM32 serial, and STM32 telemetry → `/joint_states`. Test with the 2-DOF subset.
- [ ] **Joint State Publisher GUI**: Wire it up so dragging sliders moves both the RViz model and the real arm — this is the visible demo.
- [ ] **Safety & Heartbeat**: Software watchdog that monitors connection health between Pi and STM32; emits a halt command on timeout.

---

## Checkpoint C — "It plans"

*Exit criterion: Click a goal pose in RViz, MoveIt plans, real arm executes within tolerance of the Gazebo dry-run.*

- [x] **MoveIt 2 Configuration Generation**: Use the MoveIt Setup Assistant with the preliminary URDF to generate move groups and kinematics plugins.
- [x] **MoveIt 2 Package Scaffold**: Added `robot_arm_moveit` with launch, configuration, and smoke tests.
- [ ] **MoveIt 2 Tuning**: Tune trajectory execution, allowed tolerances, and planning algorithms (OMPL) on the 2-DOF subset.
- [ ] **`FollowJointTrajectory` Action Server**: Bridge MoveIt's trajectory output to the hardware bridge node at 50–100 Hz (`docs/Constraints.md §4b`).
- [ ] **Sim/Hardware Toggle**: Single launch parameter switches the `ros2_control` plugin between `gazebo_ros2_control/GazeboSystem` and the real serial interface (`docs/implementation/software_architecture.md §4`).

---

## Checkpoint D — "It sees"

*Exit criterion: Fixed overhead camera detects a marked part on the print bed; arm picks it up using a vision-derived pose.*

- [ ] **Camera Node**: Off-the-shelf `usb_cam` or `v4l2_camera` node publishing to `/camera/image_raw`.
- [ ] **Part Localization**: ArUco-marker-based pose estimation in the bed frame (`tf2`). CV is intentionally scoped to ArUco for v1 — see `Application.md §1d`.
- [ ] **Pick Pose Service**: Converts a detected part pose into a MoveIt goal (pre-grasp → grasp → lift waypoints).
- [ ] **Gripper Control**: Action client / topic for the parallel-jaw or suction end-effector; coordinates with `MOVE_COMPLETE` telemetry from the STM32.
- [ ] **Collision Avoidance**: Static scene constraints — table, printer enclosure, bed — to prevent self-collision and printer collision (octomap optional).

---

## Checkpoint E — "It tends"

*Exit criterion: Triggering a print-complete event on the printer causes a full unattended tending cycle to execute.*

- [ ] **OctoPrint Bridge**: ROS 2 node that polls or subscribes to OctoPrint's HTTP API for the `PrintDone` event and emits a ROS event. *No CV-based completion detection — see `Application.md §1d`.*
- [ ] **Tending State Machine**: `WAITING → DETECT → APPROACH → GRASP → LIFT → PLACE → SIGNAL_NEXT_JOB → WAITING` with retry logic on missed picks (`Application.md §1b F5`).
- [ ] **Bin Pose Calibration**: One-time procedure to record the bin drop pose in the base frame.
- [ ] **Web Dashboard**: rosbridge-based interface for manual override, E-stop trigger, and cycle-count telemetry (useful for the demo video).
- [ ] **Task Logging**: Per-cycle log of timing, fault counts, and any retried picks — provides the data for the "cycle time < 60 s" soft requirement (`Application.md §1b F7`).

---

## Checkpoint F — "Sim predicted it" *(stretch)*

*Exit criterion: A single command runs the same tending sequence in Gazebo first, then on the real arm, and emits a side-by-side comparison.*

- [ ] **Dry-Run Mode**: Tending state machine accepts a `--sim-only` flag that routes execution to the Gazebo `ros2_control` plugin instead of the serial one.
- [ ] **Trajectory Diff Tool**: Replays the sim and real telemetry side by side, reports per-joint position error over time, and renders a video overlay.
- [ ] **Pre-Flight Hook**: Optional gate that runs the dry-run before every real execution and aborts if the planned trajectory violates a constraint in sim.

---

## Out-of-scope (revisit after Checkpoint E ships)

- Reinforcement learning / behavior cloning policies (`Application.md §2b` — explicitly L3/L4 are out of scope).
- Multi-printer orchestration (`Application.md §1d`).
- Generalized CV pipeline that detects arbitrary part geometries (`Application.md §1d` — v1 assumes ArUco-marked parts).

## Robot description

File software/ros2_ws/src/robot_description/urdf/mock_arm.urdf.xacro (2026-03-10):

<?xml version="1.0"?>
<robot name="mock_arm" xmlns:xacro="http://ros.org/wiki/xacro">

  <!-- A basic white material -->
  <material name="white">
    <color rgba="1 1 1 1"/>
  </material>

  <!-- A basic blue material to alternate colors and make it easier to see joints -->
  <material name="blue">
    <color rgba="0.2 0.2 0.8 1"/>
  </material>

  <!-- Base Link -->
  <link name="base_link">
    <visual>
      <geometry>
        <cylinder length="0.05" radius="0.1"/>
      </geometry>
      <material name="white"/>
    </visual>
  </link>

  <!-- Joint 1 (Base Rotation / Yaw) -->
  <joint name="joint1" type="revolute">
    <parent link="base_link"/>
    <child link="link1"/>
    <origin xyz="0 0 0.05" rpy="0 0 0"/>
    <axis xyz="0 0 1"/>
    <limit lower="-3.14" upper="3.14" effort="10" velocity="1.0"/>
  </joint>

  <!-- Link 1 (Shoulder vertical post) -->
  <link name="link1">
    <visual>
      <geometry>
        <cylinder length="0.15" radius="0.04"/>
      </geometry>
      <origin xyz="0 0 0.075" rpy="0 0 0"/>
      <material name="blue"/>
    </visual>
  </link>

  <!-- Joint 2 (Shoulder Pitch) -->
  <joint name="joint2" type="revolute">
    <parent link="link1"/>
    <child link="link2"/>
    <origin xyz="0 0 0.15" rpy="0 1.5708 0"/>
    <axis xyz="0 0 1"/> <!-- Rotates around Z because we rotated the joint origin by 90 deg (1.57 rad) in Y -->
    <limit lower="-1.57" upper="1.57" effort="10" velocity="1.0"/>
  </joint>

  <!-- Link 2 (Upper Arm) -->
  <link name="link2">
    <visual>
      <geometry>
        <cylinder length="0.2" radius="0.035"/>
      </geometry>
      <origin xyz="0 0.1 0" rpy="1.5708 0 0"/>
      <material name="white"/>
    </visual>
  </link>

  <!-- Joint 3 (Elbow Pitch) -->
  <joint name="joint3" type="revolute">
    <parent link="link2"/>
    <child link="link3"/>
    <origin xyz="0 0.2 0" rpy="0 0 0"/>
    <axis xyz="0 0 1"/>
    <limit lower="-1.57" upper="1.57" effort="10" velocity="1.0"/>
  </joint>

  <!-- Link 3 (Forearm) -->
  <link name="link3">
    <visual>
      <geometry>
        <cylinder length="0.15" radius="0.03"/>
      </geometry>
      <origin xyz="0 0.075 0" rpy="1.5708 0 0"/>
      <material name="blue"/>
    </visual>
  </link>

  <!-- Joint 4 (Wrist Pitch) -->
  <joint name="joint4" type="revolute">
    <parent link="link3"/>
    <child link="link4"/>
    <origin xyz="0 0.15 0" rpy="0 0 0"/>
    <axis xyz="0 0 1"/>
    <limit lower="-1.57" upper="1.57" effort="10" velocity="1.0"/>
  </joint>

  <!-- Link 4 (Wrist) -->
  <link name="link4">
    <visual>
      <geometry>
        <cylinder length="0.05" radius="0.035"/>
      </geometry>
      <origin xyz="0 0.025 0" rpy="1.5708 0 0"/>
      <material name="white"/>
    </visual>
  </link>

  <!-- Joint 5 (Wrist Roll) -->
  <joint name="joint5" type="revolute">
    <parent link="link4"/>
    <child link="link5"/>
    <origin xyz="0 0.05 0" rpy="0 0 1.5708"/>
    <axis xyz="0 0 1"/>
    <limit lower="-3.14" upper="3.14" effort="10" velocity="1.0"/>
  </joint>

  <!-- Link 5 (End Effector Base) -->
  <link name="link5">
    <visual>
      <geometry>
        <box size="0.04 0.04 0.04"/>
      </geometry>
      <origin xyz="0 0.02 0" rpy="0 0 0"/>
      <material name="blue"/>
    </visual>
  </link>

  <!-- Joint 6 (End Effector Roll) -->
  <joint name="joint6" type="revolute">
    <parent link="link5"/>
    <child link="link6"/>
    <origin xyz="0 0.04 0" rpy="1.5708 0 0"/>
    <axis xyz="0 0 1"/>
    <limit lower="-3.14" upper="3.14" effort="10" velocity="1.0"/>
  </joint>

  <!-- Link 6 (End Effector) -->
  <link name="link6">
    <visual>
      <geometry>
        <cylinder length="0.08" radius="0.01"/>
      </geometry>
      <origin xyz="0 0.04 0" rpy="1.5708 0 0"/>
      <material name="white"/>
    </visual>
  </link>

</robot>

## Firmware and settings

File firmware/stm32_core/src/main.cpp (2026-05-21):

#include <cstdlib>

#include <Arduino.h>

#include "control/joint_controller.h"
#include "core/types.h"
#include "drivers/encoder_driver.h"
#include "drivers/stepper_driver.h"
#include "protocol/packet_codec.h"

// --- Global driver and controller instances ---
// stepper_driver must be declared before joint_controller (constructor takes a reference).
static robot_arm::StepperDriver stepper_driver;
static robot_arm::EncoderDriver encoder_driver;
static robot_arm::JointController joint_controller(stepper_driver);
static robot_arm::PacketCodec packet_codec;

// --- Command framing constants ---
constexpr size_t kCommandFrameSize    = 28U;
constexpr size_t kHeartbeatFrameSize  = 4U;
constexpr size_t kStateFrameSize      = 52U;

constexpr unsigned long kStatePublishPeriodMs = 20UL;
constexpr unsigned long kHeartbeatTimeoutMs   = 2000UL;

static uint8_t command_frame[kCommandFrameSize]{};
static size_t command_frame_size      = 0U;
static unsigned long last_state_publish_ms = 0UL;
static unsigned long last_heartbeat_ms     = 0UL;
static unsigned long last_loop_ms          = 0UL;

#ifdef ROBOT_ARM_RENODE
constexpr size_t kRenodeCommandBufferSize = 32U;
static char renode_command_buffer[kRenodeCommandBufferSize]{};
static size_t renode_command_size = 0U;

static void handle_renode_command_line(const char* line) {
  robot_arm::JointCommand command{};
  command.target_position_deg[0] = static_cast<float>(std::strtod(line, nullptr));
  joint_controller.SetCommand(command);
  Serial.print("Received serial command: ");
  Serial.println(command.target_position_deg[0], 1);
  Serial.print("New target angle: ");
  Serial.println(command.target_position_deg[0], 2);
}
#endif

static void publish_state() {
  const robot_arm::JointState& state = joint_controller.measured_state();
  uint8_t state_frame[kStateFrameSize]{};
  const size_t encoded = packet_codec.EncodeJointState(state, state_frame, sizeof(state_frame));
  if (encoded == kStateFrameSize) {
    Serial.write(state_frame, encoded);
  }
}

void setup() {
  Serial.begin(115200);
  const unsigned long serial_wait_start_ms = millis();
  while (!Serial && (millis() - serial_wait_start_ms) < 2000UL) {
    delay(10);
  }

  Serial.println("STM32 Robot Arm Controller Initializing...");

  stepper_driver.Init();
  encoder_driver.Init();

  last_heartbeat_ms = millis();
  last_loop_ms      = millis();

  Serial.println("STM32 Robot Arm Controller Ready.");
}

void loop() {
  /*
   * MAIN CONTROL LOOP
   * This should run as fast as possible (>1000 Hz) to maintain smooth stepping.
   */

  const unsigned long now_ms = millis();
  const float dt_s = static_cast<float>(now_ms - last_loop_ms) * 0.001F;
  last_loop_ms = now_ms;

  // 1. Receive serial commands and update the joint controller target.
#ifdef ROBOT_ARM_RENODE
  while (Serial.available() > 0) {
    const int byte_value = Serial.read();
    if (byte_value < 0) {
      break;
    }

    const char received_char = static_cast<char>(byte_value);
    if (received_char == '\r') {
      continue;
    }

    if (received_char == '\n') {
      renode_command_buffer[renode_command_size] = '\0';
      if (renode_command_size > 0U) {
        handle_renode_command_line(renode_command_buffer);
      }
      renode_command_size = 0U;
      continue;
    }

    if (renode_command_size + 1U < kRenodeCommandBufferSize) {
      renode_command_buffer[renode_command_size++] = received_char;
    } else {
      renode_command_size = 0U;
    }
  }
#else
  while (Serial.available() > 0) {
    const int byte_value = Serial.read();
    if (byte_value < 0) {
      break;
    }

    if (command_frame_size == 0U && static_cast<uint8_t>(byte_value) != 0xAAU) {
      continue;
    }

    command_frame[command_frame_size++] = static_cast<uint8_t>(byte_value);
    if (command_frame_size == 2U && (command_frame[0] != 0xAAU || command_frame[1] != 0x55U)) {
      command_frame_size = 0U;
      continue;
    }

    if (command_frame_size == 3U) {
      const uint8_t command_id = command_frame[2];
      if (command_id != 0x10U && command_id != 0x12U) {
        command_frame_size = 0U;
      }
      continue;
    }

    if (command_frame_size == kHeartbeatFrameSize && command_frame[2] == 0x12U) {
      if (packet_codec.DecodeHeartbeat(command_frame, kHeartbeatFrameSize)) {
        last_heartbeat_ms = now_ms;
        publish_state();
      }
      command_frame_size = 0U;
      continue;
    }

    if (command_frame_size == kCommandFrameSize) {
      robot_arm::JointCommand decoded_command{};
      if (packet_codec.DecodeJointCommand(command_frame, kCommandFrameSize, &decoded_command)) {
        joint_controller.SetCommand(decoded_command);
        Serial.print("Received target joint 1 angle: ");
        Serial.println(decoded_command.target_position_deg[0]);
      }
      command_frame_size = 0U;
    }
  }
#endif

  // 2. Read feedback / feed measured_state_ for supervisory control & published state.
  //    EncoderDriver stays a stub unless you expose absolute angles to the MCU; CL57T holds its own inner loop.
  //    Targets are clamped in JointController (JointMotionLimits) — Tier 1.5 exercise: tune ranges / homing datum.
  robot_arm::JointState measured{};
  for (int joint = 0; joint < robot_arm::kJointCount; ++joint) {
    measured.position_deg[joint]  = encoder_driver.ReadJointAngleDeg(joint);
    measured.velocity_deg_s[joint] = 0.0F;
  }
  joint_controller.UpdateFromSensors(measured);

  // 3. Supervisory PID → velocities (JointController::Step() is a TODO scaffold until implemented).
  joint_controller.Step(dt_s);

  // 4. Emit STEP/DIR (StepperDriver::Tick() TODO scaffold — wire laurb9/StepperDriver per CONTRIBUTING.md).
  stepper_driver.Tick();

  // 5. Heartbeat watchdog: zero the command if the host goes silent.
  if ((now_ms - last_heartbeat_ms) >= kHeartbeatTimeoutMs) {
    joint_controller.SetCommand(robot_arm::JointCommand{});
  }

  // 6. Periodic state publish.
#ifndef ROBOT_ARM_RENODE
  if ((now_ms - last_state_publish_ms) >= kStatePublishPeriodMs) {
    publish_state();
    last_state_publish_ms = now_ms;
  }
#endif
}

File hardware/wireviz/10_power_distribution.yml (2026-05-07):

# 10_power_distribution
# AC mains -> IEC C14 + fuse -> latching E-stop -> Mean Well LRS-350-24
#   -> 24V_MOTOR bus -> 6 motor drivers + 3 LM2596 buck converters
# Sources: docs/implementation/electrical_design.md sec 1, electrical_interface_map.md sec 1.

connectors:
  WALL:
    type: AC mains
    subtype: wall outlet
    pinlabels: [L, N, PE]
    notes: Country-specific plug; not part of the harness BOM.

  IEC:
    type: IEC C14 inlet
    subtype: panel mount + integrated fuse holder
    pinlabels: [L, N, PE]
    notes: Fuse sized to PSU rated input current.

  ESTOP:
    type: Latching E-stop
    subtype: 1x NC contact in series with mains L
    pinlabels: [L_in, L_out]
    notes: Latching mushroom head. Cuts AC before the PSU - zero software dependency.

  PSU:
    type: Mean Well LRS-350-24
    subtype: 350 W / 24 V / 14.6 A
    pinlabels: [L, N, PE, +V1, +V2, -V1, -V2]
    notes: AC in on L/N/PE. 24V_MOTOR bus on +V/-V terminal pairs.

  TB_24V:
    type: Power distribution block
    subtype: DIN-rail terminal block (24V_MOTOR bus)
    pinlabels: [P24V_in, GND_in, P24V_drv, GND_drv, P24V_buck, GND_buck]

  BUCK_LOGIC:
    type: LM2596 buck #1
    subtype: 24V to 5V_LOGIC (~1 A)
    pinlabels: [VIN+, VIN-, VOUT+, VOUT-]
    notes: Powers STM32, 74HC245, sensors. May also power Nucleo via E5V pin.

  BUCK_PI:
    type: LM2596 buck #2
    subtype: 24V to 5V_PI (min 3 A)
    pinlabels: [VIN+, VIN-, VOUT+, VOUT-]
    notes: Dedicated to Raspberry Pi 4. Isolated from logic rail noise.

  BUCK_SERVO:
    type: LM2596 buck #3
    subtype: 24V to 5V_SERVO (MG996R only)
    pinlabels: [VIN+, VIN-, VOUT+, VOUT-]
    notes: Star-grounded at PSU return. Does NOT share with 5V_LOGIC or 5V_PI.

  LOAD_DRIVERS:
    type: Motor driver bus
    subtype: 6 drivers in parallel (CL57T x2, CL42T x2, TMC2209 x2)
    pinlabels: [P24V, GND_M]

  LOAD_LOGIC:
    type: 5V_LOGIC consumers
    subtype: STM32 / 74HC245 / sensor cluster
    pinlabels: [P5V_LOGIC, GND_L]

  LOAD_PI:
    type: Raspberry Pi 4
    subtype: USB-C or GPIO pin 2/4 + 6 (5V/GND)
    pinlabels: [P5V_PI, GND_L]

  LOAD_SERVO:
    type: MG996R servo
    subtype: gripper actuator
    pinlabels: [P5V_SERVO, GND_M]

cables:
  W_MAINS_IN:
    gauge: 14 AWG
    colors: [BN, BU, GNYE]
    length: 0.5
    wirecount: 3

  W_ESTOP_LOOP:
    gauge: 14 AWG
    colors: [BN, BU, GNYE]
    length: 0.4
    wirecount: 3
    notes: L is broken out through the E-stop; N and PE pass straight through.

  W_PSU_OUT:
    gauge: 16 AWG
    colors: [RD, RD, BK, BK]
    length: 0.4
    wirecount: 4
    notes: Two +V and two -V terminals doubled to share PSU output current.

  W_PWR_DRV_BUS:
    category: bundle
    gauge: 18 AWG
    colors: [RD, BK]
    length: 0.5
    wirelabels: [P24V, GND_M]
    notes: From terminal block to driver power inputs (chained or daisy in cabinet).

  W_PWR_TO_BUCKS:
    category: bundle
    gauge: 22 AWG
    colors: [RD, BK]
    length: 0.3
    wirelabels: [P24V, GND_M]

  W_PWR_LOGIC:
    category: bundle
    gauge: 22 AWG
    colors: [RD, BK]
    length: 0.4
    wirelabels: [P5V_LOGIC, GND_L]

  W_PWR_PI:
    category: bundle
    gauge: 18 AWG
    colors: [RD, BK]
    length: 0.4
    wirelabels: [P5V_PI, GND_L]
    notes: Sized for at least 3 A peak Pi load.

  W_PWR_SERVO:
    category: bundle
    gauge: 22 AWG
    colors: [RD, BK]
    length: 0.4
    wirelabels: [P5V_SERVO, GND_M]

connections:
  -
    - WALL: [L, N, PE]
    - W_MAINS_IN: [1-3]
    - IEC: [L, N, PE]

  -
    - IEC: [L]
    - W_ESTOP_LOOP: [1]
    - ESTOP: [L_in]
  -
    - ESTOP: [L_out]
    - W_ESTOP_LOOP: [1]
    - PSU: [L]
  -
    - IEC: [N, PE]
    - W_ESTOP_LOOP: [2, 3]
    - PSU: [N, PE]

  -
    - PSU: [+V1, +V2, -V1, -V2]
    - W_PSU_OUT: [1-4]
    - TB_24V: [P24V_in, P24V_in, GND_in, GND_in]

  -
    - TB_24V: [P24V_drv, GND_drv]
    - W_PWR_DRV_BUS: [1, 2]
    - LOAD_DRIVERS: [P24V, GND_M]

  -
    - TB_24V: [P24V_buck, GND_buck]
    - W_PWR_TO_BUCKS: [1, 2]
    - BUCK_LOGIC: [VIN+, VIN-]
  -
    - TB_24V: [P24V_buck, GND_buck]
    - W_PWR_TO_BUCKS: [1, 2]
    - BUCK_PI: [VIN+, VIN-]
  -
    - TB_24V: [P24V_buck, GND_buck]
    - W_PWR_TO_BUCKS: [1, 2]
    - BUCK_SERVO: [VIN+, VIN-]

  -
    - BUCK_LOGIC: [VOUT+, VOUT-]
    - W_PWR_LOGIC: [1, 2]
    - LOAD_LOGIC: [P5V_LOGIC, GND_L]
  -
    - BUCK_PI: [VOUT+, VOUT-]
    - W_PWR_PI: [1, 2]
    - LOAD_PI: [P5V_PI, GND_L]
  -
    - BUCK_SERVO: [VOUT+, VOUT-]
    - W_PWR_SERVO: [1, 2]
    - LOAD_SERVO: [P5V_SERVO, GND_M]

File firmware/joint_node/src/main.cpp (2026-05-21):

#include <Arduino.h>

#include "joint_node_app.h"
#include "node_config.h"

joint_node::JointNodeApp g_app;

void setup() {
  Serial.begin(115200);
  delay(500);

  const uint8_t node_id = joint_node::ResolveNodeId();
  if (node_id == 0U) {
    Serial.println("[joint_node] node_id unconfigured — use NODE_ID <1-7> or flash -e node_jN");
  }

  g_app.Setup(node_id);
}

void loop() {
  g_app.Loop();
}

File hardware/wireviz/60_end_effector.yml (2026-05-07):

# 60_end_effector
#
# End-effector / EOAT (End Of Arm Tooling). The MG996R servo IS the gripper
# actuator - it lives inside the gripper body that bolts to the J6 tool flange.
# It is NOT mounted in the arm itself.
#
# Power: dedicated 5V_SERVO rail from a third LM2596 / UBEC fed off 24V_MOTOR.
#        See 10_power_distribution.yml. Do NOT share the 5V_LOGIC or 5V_PI rails.
#
# Signal: a single PWM line from a STM32 timer pin. The MCU side does not need
#         a level shifter because the MG996R's signal pin is high-impedance and
#         triggers cleanly on 3.3 V CMOS.
#
# Optional: a Force Sensitive Resistor (FSR) on the gripper fingertips for
#           grip-force feedback (mechanical_design.md sec 5).
#
# Sources:
#   docs/implementation/mechanical_design.md sec 5
#   docs/implementation/electrical_interface_map.md sec 5

connectors:
  MCU:
    type: STM32 Nucleo-F401RE
    subtype: 1x PWM-capable timer pin + optional ADC for FSR
    pinlabels:
      - PA8        # TIM1_CH1 (gripper PWM, ~50 Hz hobby servo frame)
      - GND_L
      - PA0        # ADC1_IN0 (optional FSR analog input)

  BUCK_SERVO:
    type: LM2596 buck #3
    subtype: 24V to 5V_SERVO (gripper only)
    pinlabels: [VOUT_p, VOUT_n]

  TOOL_FLANGE:
    type: Tool flange harness pass-through
    subtype: 4-pin connector at the J6 wrist (panel mount)
    pinlabels: [P5V_SERVO, GND_M, PWM, FSR]
    notes: All EOAT signals cross the wrist here. Use a locking connector so a tool change does not yank the arm wiring.

  GRIPPER:
    type: MG996R metal-gear servo
    subtype: integrated into the gripper body (not the arm)
    pinlabels: [P5V_SERVO, GND_M, PWM]
    notes: |
      The MG996R is THE gripper actuator. Mount it inside / on the
      3D-printed gripper assembly that bolts to the J6 tool flange,
      NOT in the arm wrist. Standard 3-wire hobby servo pinout.

  FSR:
    type: Force Sensitive Resistor (OPTIONAL)
    subtype: glued to the gripper fingertip pad
    pinlabels: [SIG, GND_L]
    notes: Voltage divider with a 10k resistor on the controller board feeds an ADC pin.

cables:
  W_SERVO_PWR:
    category: bundle
    wirelabels: [P5V_SERVO, GND_M]
    gauge: 22 AWG
    colors: [RD, BK]
    length: 0.4
    notes: From the dedicated buck output to the tool flange P5V_SERVO/GND_M pins.

  W_SERVO_PWM:
    category: bundle
    wirelabels: [PWM, GND_L]
    gauge: 24 AWG
    colors: [OG, BK]
    shield: true
    length: 1.5
    notes: STM32 PWM signal routed through the arm to the tool flange. Keep separate from motor phase cables.

  W_FSR:
    category: bundle
    wirelabels: [SIG, GND_L]
    gauge: 26 AWG
    colors: [WH, BK]
    shield: true
    length: 1.5

  W_TOOL_PIGTAIL:
    category: bundle
    wirelabels: [P5V_SERVO, GND_M, PWM, FSR]
    gauge: 24 AWG
    colors: [RD, BK, OG, WH]
    length: 0.2
    notes: Short pigtail inside the gripper from the tool-flange connector to the MG996R and FSR.

connections:
  - [BUCK_SERVO: [VOUT_p, VOUT_n], W_SERVO_PWR: [1, 2], TOOL_FLANGE: [P5V_SERVO, GND_M]]
  - [MCU: [PA8, GND_L], W_SERVO_PWM: [1, 2], TOOL_FLANGE: [PWM, GND_M]]
  - [MCU: [PA0, GND_L], W_FSR: [1, 2], TOOL_FLANGE: [FSR, GND_M]]

  - [TOOL_FLANGE: [P5V_SERVO, GND_M, PWM], W_TOOL_PIGTAIL: [1-3], GRIPPER: [P5V_SERVO, GND_M, PWM]]
  - [TOOL_FLANGE: [FSR, GND_M], W_TOOL_PIGTAIL: [4, 2], FSR: [SIG, GND_L]]

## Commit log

2026-03-10 feat: add initial project structure including ROS2 packages, documentation, and development tools.
    [mock_arm.urdf.xacro]
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2026-03-16 feat: update BOM with detailed vendor links and specifications for robot arm components
2026-03-17 Remove build logs and latest build references for robot_core and robot_description components
    [mock_arm.urdf.xacro]
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2026-03-20 feat: Extend cycloidal drives to J3 and J4 with specific ratios, standardizing gearing across all driven joints, and detail vibration mitigation strategies.
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2026-03-26 Add Renode installation and simulation scripts for STM32F401RE
    - Introduced `install-renode.py` script for automated Renode installation.
    - Created README.md for Renode STM32F401RE scaffold with usage instructions.
    - Added `nucleo_f401re.resc` configuration for Renode simulation.
    - Implemented firmware smoke test in Robot Framework.
    - Developed PowerShell and Bash scripts for running Renode simulations.
    - Added test scripts for executing pytest in the simulation environment.
    - Included build scripts for invoking the development build process.
    - Added a snapshot for firmware smoke test failure for debugging purposes.
    [main.cpp]
2026-03-27 Add MoveIt scaffold and ROS workflow
    [joint_limits.yaml]
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2026-03-27 Add initial version of joint1 cycloidal disk model
    [joint1-cycloidal-disk.SLDPRT]
2026-03-27 Refactor trapezoidal profile generation and enhance tests
    - Updated trapezoidal_profile.py to ensure that start and goal joint values are copied correctly.
    - Added a new test to verify that modifying the input lists does not affect the generated trajectory points.
    - Removed unnecessary cached .pyc files and binary snapshot files.
    - Introduced new tests for the DH model and DH solver to validate forward kinematics and transformation matrices.
    - Enhanced existing tests in the robot_core and robot_arm_moveit packages to ensure proper functionality and error handling.
    - Updated CMakeLists.txt to include additional linting tools for code quality checks.
    [test_driver_scaffolds.cpp]
2026-03-27 Update joint1 cycloidal disk model file with dual disk
    [joint1-cycloidal-disk.SLDPRT]
2026-03-27 Add initial version of joint1 shaft adapter part file
    [joint1-shaft-adapter.SLDPRT]
2026-03-28 Update joint1 shaft adapter part file with clamp
    [joint1-shaft-adapter.SLDPRT]
2026-03-30 Updated eccentric shaft design
    [joint-1-cycloidal-drive.SLDASM, joint1-cycloidal-disk.SLDPRT, joint1-eccentric-cam1.SLDPRT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]
2026-03-30 Initial design of joint 1 output disk
    [joint1-output-disk.SLDPRT]
2026-03-30 Initial housing design
    [joint1-cycloidal-housing.SLDPRT, joint1-output-disk.SLDPRT]
2026-03-30 Started joint 1 cycloidal drive assembly
    [6002-bearing.SLDPRT, joint1-cycloidal-disk.SLDPRT, joint1-cycloidal-disk1.SLDPRT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]
2026-04-03 Added lid and updated dimensions for joint 1
    [6004-bearing.SLDPRT, disk-connector-pin-3x25.SLDPRT, joint1-cycloidal-disk.SLDPRT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]
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2026-04-30 initial drawings + exploded view
    [6002-bearing.SLDPRT, 6004-bearing.SLDPRT, joint1-cycloidal-disk.SLDPRT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]
2026-05-04 motor mounting plate for housing redesign + added global variables
    [joint1-cycloidal-disk.SLDPRT, joint1-cycloidal-housing.SLDDRW, joint1-cycloidal-housing.SLDPRT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]
2026-05-05 feat(hardware): KiCad drafts, datasheet bundle, Nucleo-F401RE PIO target
    - Document frozen electrical choices (six ALARM lines, 5V_SERVO rail, CL 5V TTL,
    Nucleo-F401RE); fix 74HC245 note and align pinout/electrical docs.
    - Add KiCad project under hardware/kicad/robot_arm (net classes, subsheets,
    generate_schematics.py, README, driver interface notes); link from schematic plan.
    - Populate hardware/datasheets with vendor/mirror PDFs; README lists source URLs;
    remove automated fetch script; trim root README hardware line.
    - Switch PlatformIO to board nucleo_f401re / nucleo_f401re_renode; update CI,
    Renode scripts, firmware build scripts, copilot instructions, firmware README.
    [logic_power.kicad_sch, motor_joint_J1.kicad_sch, motor_joint_J2.kicad_sch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]
2026-05-05 added link 1
    [joint1-cycloidal-drive.SLDASM, joint1-motor-mounting-plate.SLDPRT, link1.SLDPRT]
2026-05-05 eccentric cam improved spacing and tighter fit
    [joint1-cycloidal-drive.SLDASM, joint1-eccentric-cam1.SLDPRT, joint1-eccentric-cam2.SLDPRT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]
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2026-05-05 fix(ci): Remove hardware_test_main.cpp from build source filter in platformio.ini
2026-05-05 docs: Update documentation and schematics to reflect transition from Raspberry Pi 3 to Raspberry Pi 4 for high-level control and power management. Adjusted references in README, calculations, design 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
    [logic_power.kicad_sch, stm32_control.kicad_sch]
2026-05-06 cycloidal housing redesign with flange and smaller ID
    [joint1-cycloidal-drive.SLDASM, joint1-cycloidal-housing.SLDPRT, joint1-eccentric-cam1.SLDPRT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]
2026-05-06 added mounting holes for link on cycloidal housing
    [joint1-cycloidal-housing.SLDPRT]
2026-05-06 docs: Enhance README and CI configuration for portability and clarity
    - Updated README files to clarify the use of repository-relative paths and the importance of rerunning setup scripts after moving the clone directory.
    - Modified CI workflow to include specific firmware build and testing paths, ensuring compatibility with Renode smoke tests.
    - Adjusted VS Code configuration to improve include paths for STM32 libraries.
    - Added onboarding instructions in firmware README to prevent committing generated files and to emphasize path resolution from script locations.
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2026-05-06 refactor: Update wiring diagrams for control signals and joint configurations
    - Simplified pin labels and notes in `20_control_signals.yml` for clarity.
    - Split TMC2209 wiring into logical blocks in `40_joint_J5_open_loop.yml` for better organization.
    - Removed `50_sensor_bus.yml` as it is no longer needed; updated README to reflect this change and clarify the role of AS5600 encoders.
    - Enhanced connection definitions for clarity and consistency across joint configurations.
    [20_control_signals.yml, 30_joint_J1_closed_loop.yml, 40_joint_J5_open_loop.yml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]
2026-05-07 added cutouts for hall effect sensor and magnet in output disk and lid
    [joint-1-cycloidal-drive.SLDASM, joint1-cycloidal-drive.SLDASM, joint1-cycloidal-housing.SLDPRT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]
2026-05-07 manual motor testing components
    [joint1-motor-test-plate.SLDPRT, joint1-testing-crank.SLDPRT]
2026-05-08 new lid version for testing and changes to j1 cycloidal drive dimensions based on testing
    [joint1-cycloidal-disk.SLDPRT, joint1-cycloidal-lid.SLDPRT, joint1-output-disk.SLDPRT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]
2026-05-08 fixed joint 1 cycloidal housing pins and added joint 2 cycloidal disks
    [joint1-cycloidal-disk.SLDPRT, joint1-cycloidal-disk1.SLDPRT, joint1-cycloidal-disk2.SLDPRT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]
2026-05-10 joint 2 cycloidal drive components for nema 23 motor
    [joint2-cycloidal-disk.SLDPRT, joint2-cycloidal-disk1.SLDPRT, joint2-cycloidal-housing.SLDPRT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]
2026-05-11 updated expenses with j2 nema 23 + accessories and added motor step file to j2 assembly
    [joint2.SLDASM, nema23.STEP]
2026-05-13 link 2 draft + widened j2 mounting plate flange
    [joint2-motor-mounting-plate.SLDPRT, joint2.SLDASM, link2.SLDPRT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]
2026-05-14 j1 and j2 motor mounting plates modified for proper hex nut tightening
    [joint1-motor-mounting-plate.SLDPRT, joint1.SLDASM, joint2-motor-mounting-plate.SLDPRT]
2026-05-14 updated j1 link flange to match mounting plate
    [joint1.SLDASM, link1.SLDPRT]
2026-05-14 updated expenses with 20mm, 25mm and 50mm M5 bolts
    [link1.SLDPRT]
2026-05-14 updated j1 cycloidal housing flange
    [joint1-cycloidal-housing.SLDPRT, joint1.SLDASM]
2026-05-14 added link 2 details
    [joint1-cycloidal-housing.SLDPRT, joint1.SLDASM, joint2.SLDASM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]
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2026-05-14 changed m3 bolts to m4 for cycloidal housing to lid connection and added counterbores
    [joint-1-cycloidal-drive.SLDASM, joint1-cycloidal-housing.SLDPRT, joint1-cycloidal-lid.SLDPRT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]
2026-05-14 added bolt hole and counterbore for nut to output disk shaft and added magnet cutouts at different distances for testing
    [joint1-output-disk.SLDPRT, link2.SLDPRT]
2026-05-15 updated j2 cycloidal housing holes to match j1 dimensions
    [joint1-cycloidal-housing.SLDPRT, joint2-cycloidal-housing.SLDPRT, joint2.SLDASM]
2026-05-15 fixed j1 output disk to link 2 connection lengths + tolerances and added slot to hold hex nut in place
    [joint1-output-disk.SLDPRT, joint1.SLDASM, joint2-cycloidal-disk.SLDPRT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]
2026-05-15 added clearance hole near base of j2 and nut trap to flange for bolt connecting it to the mounting plate and cycloidal housing to fit
    [joint1-output-disk.SLDPRT, link2.SLDPRT]
2026-05-16 modified j2 cycloidal housing to lid connection to m4, completed j2 assembly
    [joint1.SLDASM, joint2-cycloidal-housing.SLDPRT, joint2-output-disk.SLDPRT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]
2026-05-16 updated j2 eccentric cam 1 base height to account for mounting bracket thickness and extended bolt hole for easier fit
    [joint2-eccentric-cam1.SLDPRT]
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2026-05-18 Add OSS legal files, README refresh, and firmware dependency cleanup
    LICENSE, NOTICE, SECURITY, CONTRIBUTING, and TESTING; README with CI badge
    and corrected paths; Simulink planned banners; datasheet PDFs removed from git
    (URL list only). Replace GPL AccelStepper with MIT laurb9/StepperDriver.
    [joint1-motor-mounting-plate - Copy (2).SLDPRT]
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2026-05-21 added fillet between the top and middle sections of j2 eccentric cam 1 to prevent shear
    [joint2-eccentric-cam1.SLDPRT, joint2.SLDASM]
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2026-05-26 Enhance hardware test documentation and scripts for Hall sensor and RS-485
    - Added `run_hall_arduino.sh` and `run_hall.sh` scripts for testing Hall sensors on Arduino and Nucleo, respectively, with detailed usage instructions in `README.md`.
    - Updated `run_rs485.sh` to include a check for ST-Link connectivity before flashing.
    - Deprecated the previous Hall sensor Arduino firmware in favor of the new testing scripts.
    - Updated wiring documentation to emphasize the importance of CN2 jumpers for Nucleo uploads.
    - Modified `platformio.ini` to support uploading under reset for improved reliability.
    - Integrated Hall sensor test into the main hardware test framework in `hardware_test_main.cpp`.
    [hardware_test_main.cpp, main.ino, pinout.h]
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2026-05-28 updated j2 eccentric cam to form-fit D-profile shaft and changed dimensions to prevent cracks
    [joint1-testing-crank-form-fit.SLDPRT, joint2-eccentric-cam1.SLDPRT, joint2.SLDASM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]
2026-05-28 changed testing lid tolerance for tighter fit to keep bearing from slipping
    [joint1-testing-cycloidal-lid.SLDPRT]
2026-05-28 added bottom section of link 3
    [joint1.SLDASM, joint3.SLDASM, link3-part1.SLDPRT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]
2026-05-28 added link 3 section 2
    [CL42T-V41.STEP, joint3.SLDASM, link3-part1.SLDPRT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]
2026-05-29 Update firmware README.md with STM32 flashing instructions and hardware test details
    - Added section for flashing STM32 (Nucleo-F401RE) with usage instructions for upload scripts.
    - Included manual upload commands and troubleshooting steps for connection issues.
    - Documented separate hardware test images and their corresponding README for clarity.
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2026-07-04 Enhance RS-485 log hub and ESP32 bench scripts
    - Updated `rs485_log_hub.py` to include a `--no-pico` option for UDP-only logging without opening a serial port.
    - Modified `platformio.ini` to change the board to `lolin_c3_mini` and adjusted monitor settings.
    - Refined `main.cpp` to improve status LED handling and added boot messages for better debugging.
    - Updated `pinout.h` to disable the status LED by default to prevent conflicts on certain boards.
    - Changed Wi-Fi password in `wifi_config.h` for security.
    - Enhanced Wi-Fi connection logic in `wifi_log.cpp` to include a retry mechanism for improved reliability.
    [main.cpp, pinout.h, rs485_log_hub.py]
2026-07-04 Remove sensitive Wi-Fi configuration and enhance logging in ESP32 bench scripts
    - Deleted `wifi_config.h` to prevent accidental exposure of Wi-Fi credentials.
    - Updated `.gitignore` to exclude local bench credentials and configuration files.
    - Improved Wi-Fi connection logic in `wifi_log.cpp` with enhanced diagnostics and retry mechanisms for better reliability.
2026-07-11 Enhance RS-485 ESP32 bench scripts and logging functionality
    - Added `find_esp_port` function to automatically detect the correct ESP32 serial port, preventing accidental flashing of the Pico.
    - Updated `flash_rs485_esp32_nodes.sh` to utilize the detected port for flashing.
    - Enhanced `rs485_log_hub.py` with new commands for motor control (run, jog, bench, wave) and improved status reporting to include motor state.
    - Refined logging in `wifi_log.cpp` to batch and coalesce high-rate RX commands, improving UDP transmission efficiency.
    - Updated documentation in `rs485_bench_protocol.h` to reflect new command capabilities and usage examples.
    [main.cpp, pinout.h, rs485_log_hub.py]
2026-07-13 link 3 part 2
    [CL42T-V41.SLDPRT, base.SLDPRT, joint3.SLDASM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]
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
